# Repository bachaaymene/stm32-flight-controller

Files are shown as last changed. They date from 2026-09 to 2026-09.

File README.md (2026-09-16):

# STM32F405 Flight Controller

A 4-layer flight controller board for an F450 quadcopter frame, based on the STM32F405RGT6. Designed in KiCad 10 by [SparkLab DZ](https://sparklabdz.com).

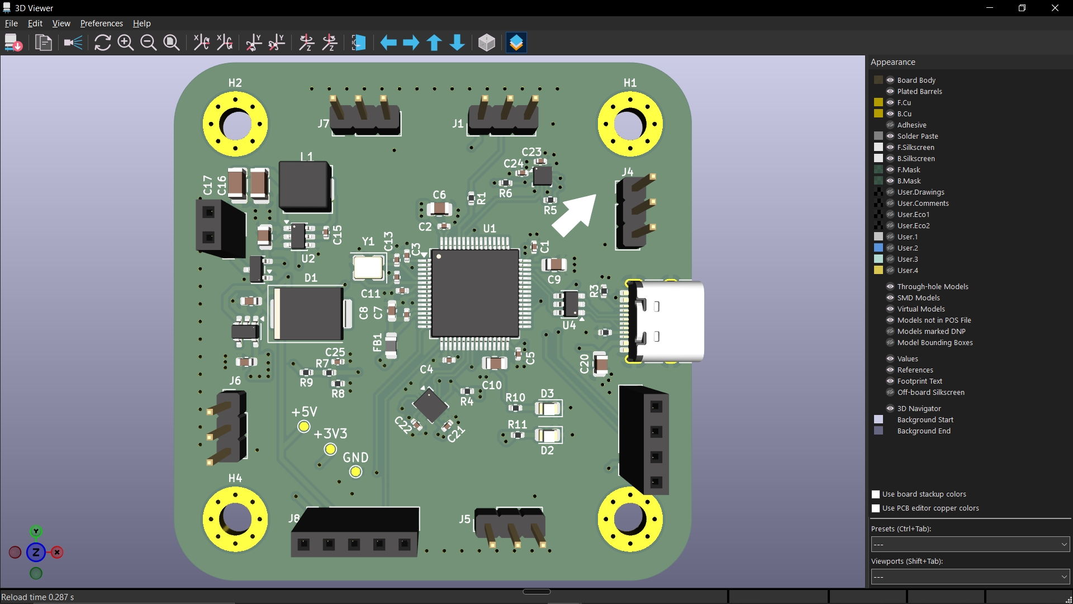
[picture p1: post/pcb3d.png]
3D render


## Features

| Block | Part | Notes |
|---|---|---|
| MCU | STM32F405RGT6 (LQFP64) | Cortex-M4F, 168 MHz, 1 MB Flash |
| IMU | LSM6DSO | SPI1, INT1 on PC4 |
| Barometer | LPS22HB | I2C1, address 0x5C |
| Motor outputs | 4x ESC | PC6 to PC9 on TIM3 (DShot capable) |
| 5V regulator | AP63205WU-7 | Synchronous buck, 3S LiPo input, 4.7 uH inductor |
| 3.3V regulator | TLV70233 | LDO from 5V |
| USB | USB Type-C 16P | PA11 / PA12 |
| Battery sense | 33k / 10k divider | PA0 (ADC) |

## Schematic

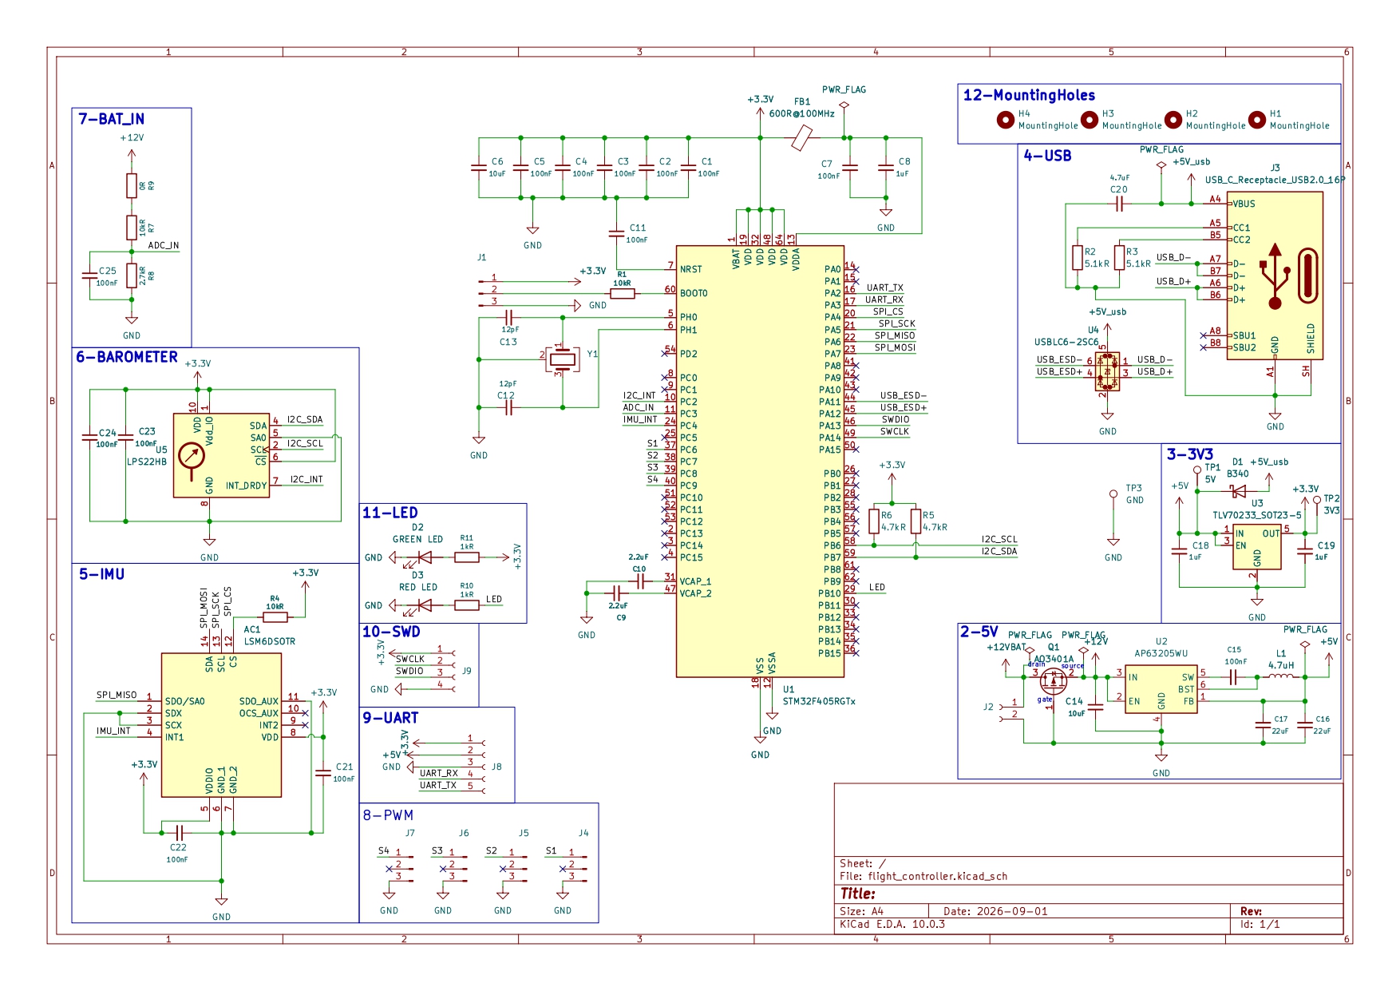
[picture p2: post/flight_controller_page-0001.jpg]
Schematic


Full schematic as PDF: [post/flight_controller.pdf](post/flight_controller.pdf)

## PCB Layout

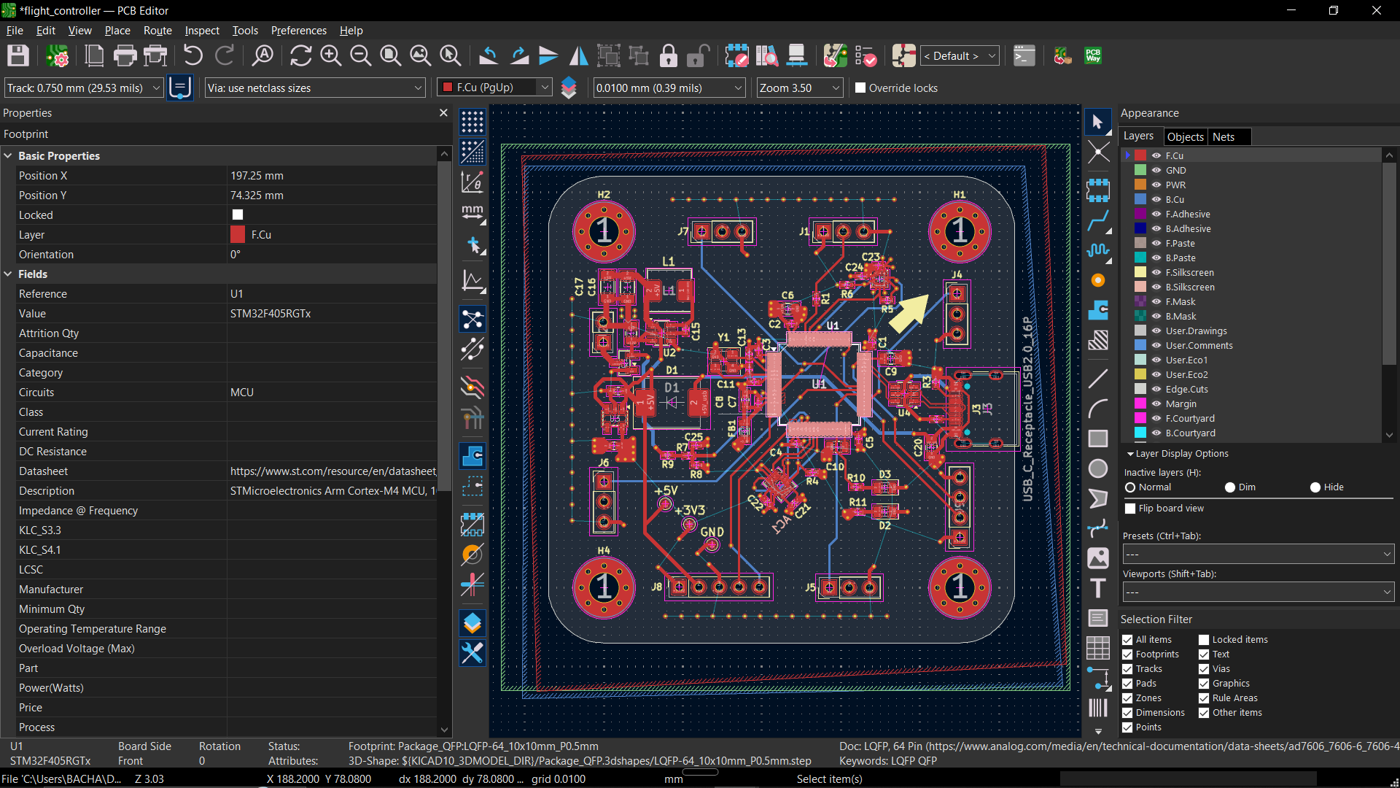
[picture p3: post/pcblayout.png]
PCB layout


### Stackup

| Layer | Use |
|---|---|
| L1 | Signal + components |
| L2 | Solid GND plane |
| L3 | Power |
| L4 | Signal |

## Pin Map

| Function | Pin(s) |
|---|---|
| IMU SPI1 (CS / SCK / MISO / MOSI) | PA4 / PA5 / PA6 / PA7 |
| IMU interrupt (INT1) | PC4 |
| Baro I2C1 (SCL / SDA) | PB6 / PB7 |
| ESC 1 to 4 | PC6 / PC7 / PC8 / PC9 |
| USB D- / D+ | PA11 / PA12 |
| Battery voltage | PA0 |

Pin configuration in STM32CubeIDE:

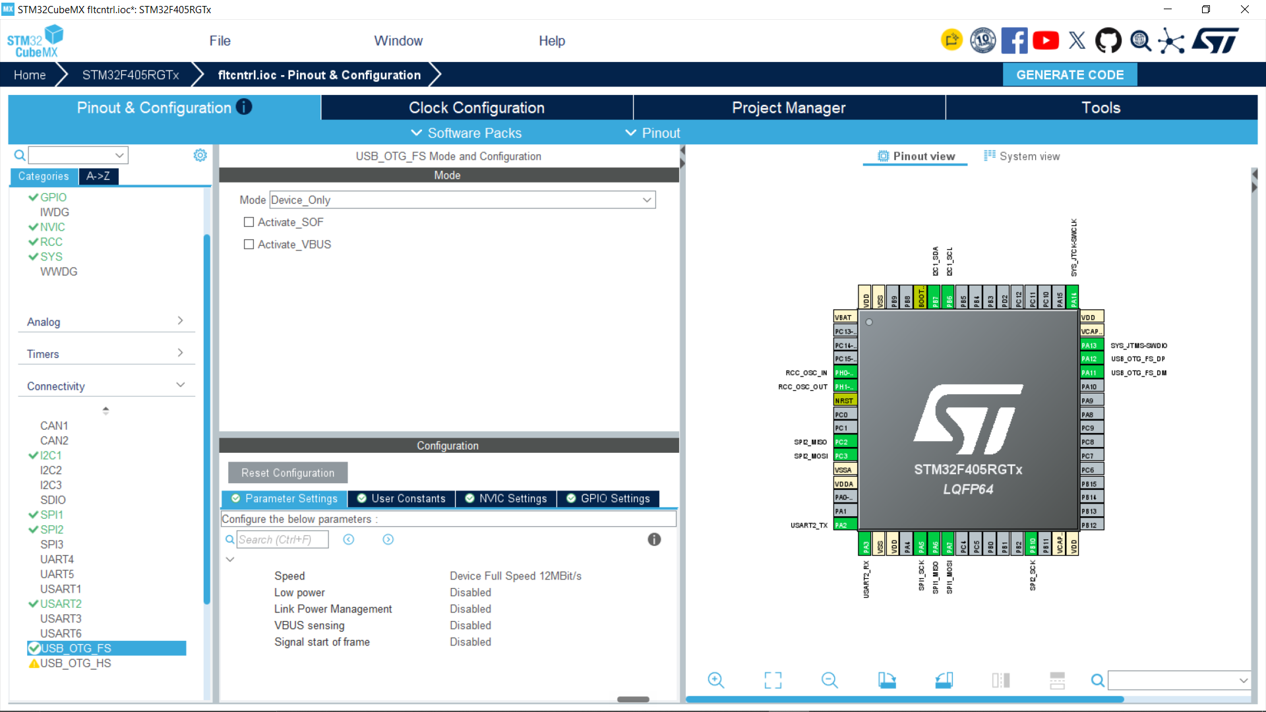
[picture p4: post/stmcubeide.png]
STM32CubeIDE pinout


## Repository Structure

```
stm32-flight-controller/
├── datasheets/                      Component datasheets
├── libs/                            Project symbols, footprints and 3D models
├── post/                            Schematic PDF and images
├── flight_controller.kicad_pro      KiCad project
├── flight_controller.kicad_sch      Schematic
├── flight_controller.kicad_pcb      PCB layout
├── flight_controller.csv            Bill of materials
├── fabrication-toolkit-options.json Fabrication Toolkit plugin settings
├── sym-lib-table                    Project symbol library table
├── fp-lib-table                     Project footprint library table
├── .gitattributes                   Git LFS settings
└── .gitignore
```

## Opening the Project

Requirements: **KiCad 10.0 or newer**. Older versions cannot open these files.

The repository uses Git LFS for large files, so install it before cloning:

```bash
git lfs install
git clone https://github.com/bachaaymene/stm32-flight-controller.git
```

Then open `flight_controller.kicad_pro` in KiCad.

All symbols, footprints and 3D models are stored in `libs/` with paths relative to the project (`${KIPRJMOD}`), so no external libraries are needed. If something appears missing, please open an issue.

## Manufacturing

The BOM is in `flight_controller.csv`.

Production files (Gerber, drill, BOM and CPL) for JLCPCB can be generated with the [Fabrication Toolkit](https://github.com/bennymeg/Fabrication-Toolkit) plugin. Install it from the KiCad Plugin and Content Manager, then run it from the PCB editor. The settings used for this board are saved in `fabrication-toolkit-options.json`.

## Status

- [x] Schematic
- [x] PCB layout
- [ ] Prototype fabrication
- [ ] Hardware bring-up
- [ ] Firmware

## License

This hardware design is released under the [CERN-OHL-S-2.0](LICENSE) license.

## Author

Aymene Bacha, [SparkLab DZ](https://sparklabdz.com)

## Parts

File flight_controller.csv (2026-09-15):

# | Reference | Qty | Manufacturer | Value | Description | Footprint | Circuits | LCSC
1 | AC1 | 1 |  | LSM6DSOTR | 6-axis IMU (inertial measurement unit): always-on 3axis accelerometer and 3axis gyroscope | Package_LGA:LGA-14_3x2.5mm_P0.5mm_LayoutBorder3x4y | IMU | C2655100
2 | C1,C2,C3,C4,C5,C7,C11,C15,C21,C22,C23,C24,C25 | 13 |  | 100nF | 100nF 0402 16V X7R | Capacitor_SMD:C_0402_1005Metric | Barometrer: Decoupling VDD,Barometrer: Decoupling VDDA,Bootstrap,Decoupling VBAT,Decoupling VDD,IMU: Decoupling VDD,IMU: Decoupling VDDA,NRST ,USB VBUS.,VDDA | C60474
3 | C6,C14 | 2 |  | 10uF | 10uF 0805 16V X5R,10uF 0805 25V X5R | Capacitor_SMD:C_0805_2012Metric | Buck input,Bulk Decoupling | C386085,C77075
4 | C8,C18,C19 | 3 |  | 1uF | 1uF 0603 16V X7R | Capacitor_SMD:C_0603_1608Metric | LDO input,LDO output,VDDA | C59782
5 | C9,C10 | 2 |  | 2.2uF | 2.2uF 0805 16V X5R | Capacitor_SMD:C_0805_2012Metric | Core regulator | C1731
6 | C12,C13 | 2 |  | 12pF | 12pF 0402 10V C0G | Capacitor_SMD:C_0402_1005Metric | Crystal load capacitors | C3899757
7 | C16,C17 | 2 |  | 22uF | 22uF 1206 25V X5R | Capacitor_SMD:C_1206_3216Metric | Buck output capacitors. | C7432785
8 | C20 | 1 |  | 4.7uF | 4.7uF 0805 16V X5R | Capacitor_SMD:C_0805_2012Metric | VBUS bulk | C1746
9 | D1 | 1 |  | B340 | 40V 3A Schottky Barrier Rectifier Diode, SMC | Diode_SMD:D_SMC | USB isolation | C388236
10 | D2 | 1 |  | GREEN LED | Light emitting diode | LED_SMD:LED_0805_2012Metric | Power indicator | C84260
11 | D3 | 1 |  | RED LED | Light emitting diode | LED_SMD:LED_0805_2012Metric | Status indicator | C2971979
12 | FB1 | 1 |  | 600R@100MHz | 300mR ±25% 600R@100MHz 0805 | Inductor_SMD:L_0805_2012Metric | VDDA isolation | C527966
13 | J1,J4,J5,J6,J7 | 5 |  | Conn_01x03_Pin | Generic connector, single row, 01x03, script generated | Connector_PinHeader_2.54mm:PinHeader_1x03_P2.54mm_Vertical | BOOT0,PWM
14 | J2 | 1 |  | Conn_01x02_Socket | Generic connector, single row, 01x02, script generated | Connector_PinSocket_2.54mm:PinSocket_1x02_P2.54mm_Vertical | Battery 12V
15 | J3 | 1 |  | USB_C_Receptacle_USB2.0_16P | USB 2.0-only 16P Type-C Receptacle connector | Connector_USB:USB_C_Receptacle_HRO_TYPE-C-31-M-12 | USB | C2988369
16 | J8 | 1 |  | Conn_01x05_Socket | Generic connector, single row, 01x05, script generated | Connector_PinSocket_2.54mm:PinSocket_1x05_P2.54mm_Vertical | UART
17 | J9 | 1 |  | Conn_01x04_Socket | Generic connector, single row, 01x04, script generated | Connector_PinSocket_2.54mm:PinSocket_1x04_P2.54mm_Vertical | SWD
18 | L1 | 1 |  | 4.7uH | 4.7uH, Isat 4.6A, DCR 60mR | Inductor_SMD:L_Sunlord_MWSA0503S | Buck inductor | C5349683
19 | Q1 | 1 |  | AO3401A | -4.0A Id, -30V Vds, P-Channel MOSFET, SOT-23 | Package_TO_SOT_SMD:SOT-23 | Reverse protection | C15127
20 | R1,R4,R7 | 3 |  | 10kR | 10kR 0402 | Resistor_SMD:R_0402_1005Metric | BOOT0,CS pull-up,Sense divider | C60490
21 | R2,R3 | 2 |  | 5.1kR | 5.1kR 0402 ±1% | Resistor_SMD:R_0402_1005Metric | CC pull-downs | C105872
22 | R5,R6 | 2 |  | 4.7kR | 4.7kR 0402 ±1% | Resistor_SMD:R_0402_1005Metric | I2C pull-ups | C105871
23 | R8 | 1 |  | 2.7kR | 2.7kR 0402 | Resistor_SMD:R_0402_1005Metric | Sense divider | C138017
24 | R9 | 1 |  | 0R | 0R 0402 | Resistor_SMD:R_0402_1005Metric | Sense isolation | C106231
25 | R10,R11 | 2 |  | 1kR | 1kR 0402 | Resistor_SMD:R_0402_1005Metric | LED current limit | C106235
26 | TP1 | 1 |  | 5V | test point | TestPoint:TestPoint_Pad_D1.0mm
27 | TP2 | 1 |  | 3V3 | test point | TestPoint:TestPoint_Pad_D1.0mm
28 | TP3 | 1 |  | GND | test point | TestPoint:TestPoint_Pad_D1.0mm
29 | U1 | 1 |  | STM32F405RGTx | STMicroelectronics Arm Cortex-M4 MCU, 1024KB flash, 192KB RAM, 168 MHz, 1.8-3.6V, 51 GPIO, LQFP64 | Package_QFP:LQFP-64_10x10mm_P0.5mm | MCU | C15742
30 | U2 | 1 |  | AP63205WU | 2A, 1.1MHz Buck DC/DC Converter, fixed 5.0V output voltage, TSOT-23-6 | Package_TO_SOT_SMD:TSOT-23-6 | 5V buck | C15742
31 | U3 | 1 |  | TLV70233_SOT23-5 | 300mA Low Dropout Voltage Regulator, Fixed Output 3.3V, SOT-23-5 | Package_TO_SOT_SMD:SOT-23-5 | 3V3 LDO | C26833
32 | U4 | 1 |  | USBLC6-2SC6 | Very low capacitance ESD protection diode, 2 data-line, SOT-23-6 | Package_TO_SOT_SMD:SOT-23-6 | USB ESD | C2827654
33 | U5 | 1 |  | LPS22HB | MEMS nano pressure sensor, 260-1260 hPa, absolute digital output baromeeter, 24 bit, SPI, I2C, 0.0075 hPa noise rms, ST_HLGA-10L | Package_LGA:ST_HLGA-10_2x2mm_P0.5mm_LayoutBorder3x2y | Pressure sensor | C94049
34 | Y1 | 1 |  | 8MHz Crystal_GND24 | 8MHz 10pF Four pin crystal, GND on pins 2 and 4 | Crystal:Crystal_SMD_3225-4Pin_3.2x2.5mm | HSE clock | C400090

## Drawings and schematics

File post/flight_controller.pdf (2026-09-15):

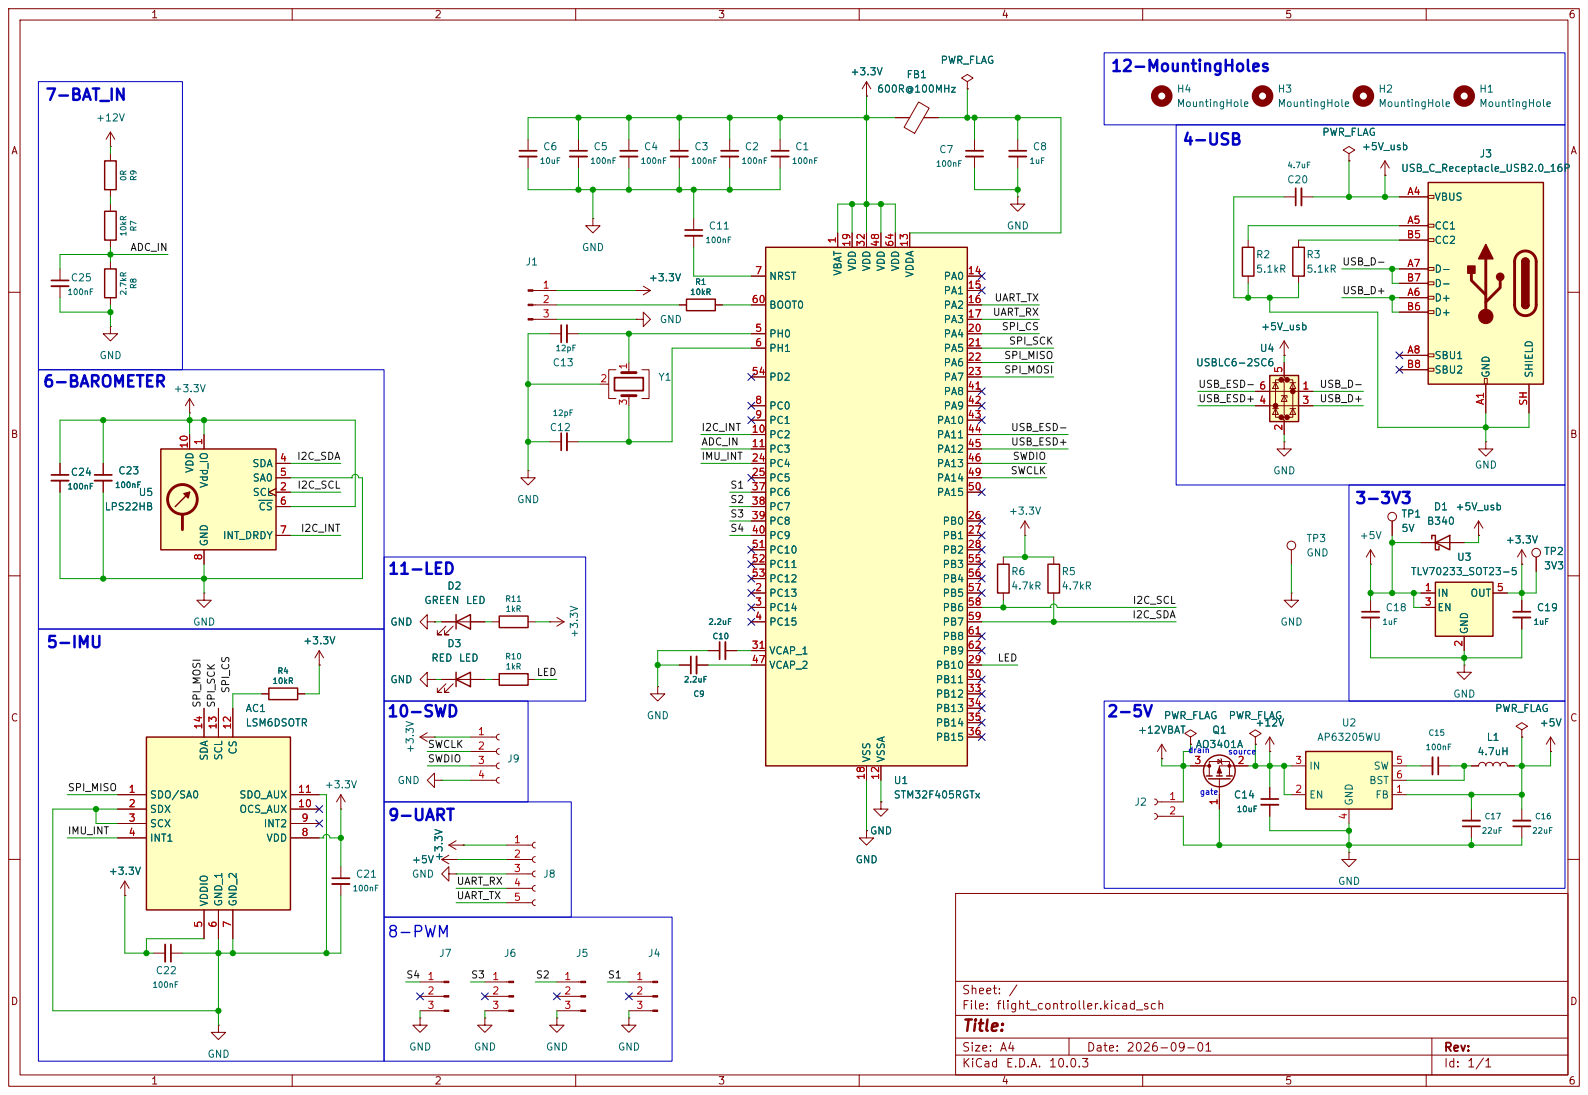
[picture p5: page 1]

Size: A4 | Rev:
KiCad E.D.A. 10.0.3 | Id: 1/1

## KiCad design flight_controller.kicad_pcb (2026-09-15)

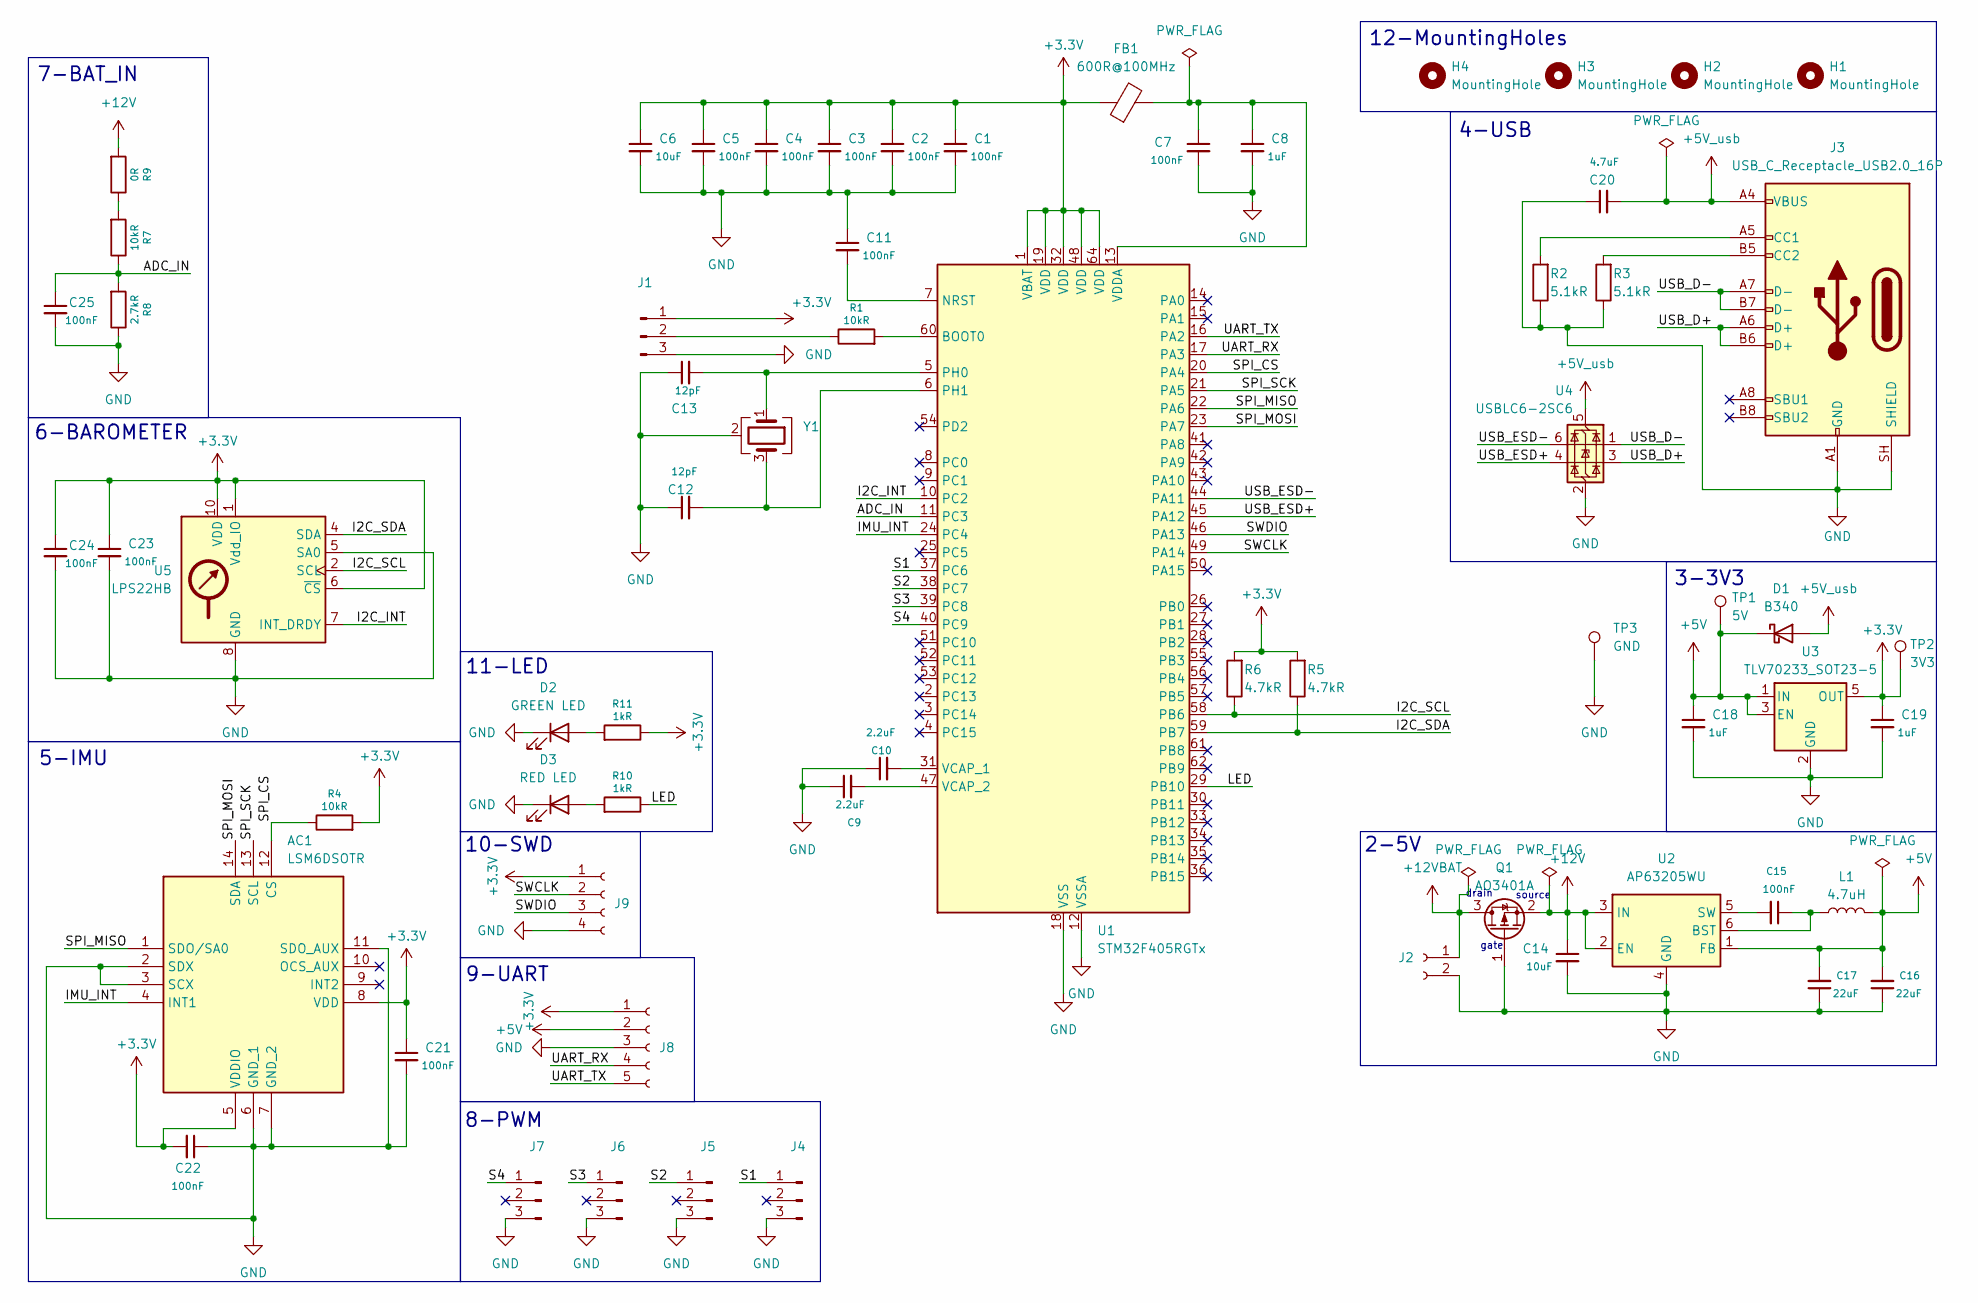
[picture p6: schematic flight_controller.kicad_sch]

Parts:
AC1: LSM6DSOTR; LGA-14_3x2.5mm_P0.5mm_LayoutBorder3x4y; Manufacturer_Part_Number LSM6DSOTR; Mouser Part Number 511-LSM6DSOTR
C1, C2, C3, C4, C5, C7, C11, C15, C21, C22, C23, C24, C25: 100nF; C_0402_1005Metric; LCSC C60474
C6: 10uF; C_0805_2012Metric; LCSC C77075
C8, C18, C19: 1uF; C_0603_1608Metric; LCSC C59782
C9, C10: 2.2uF; C_0805_2012Metric; LCSC C1731
C12, C13: 12pF; C_0402_1005Metric; LCSC C3899757
C14: 10uF; C_0805_2012Metric; LCSC C386085
C16, C17: 22uF; C_1206_3216Metric; LCSC C7432785
C20: 4.7uF; C_0805_2012Metric; LCSC C1746
D1: B340; D_SMC; LCSC C388236
D2: GREEN LED; LED_0805_2012Metric; LCSC C84260
D3: RED LED; LED_0805_2012Metric; LCSC C2971979
FB1: 600R@100MHz; L_0805_2012Metric; LCSC C527966
H1, H2, H3, H4: MountingHole; MountingHole_3.7mm_Pad_Via
J1, J4, J5, J6, J7: Conn_01x03_Pin; PinHeader_1x03_P2.54mm_Vertical
J2: Conn_01x02_Socket; PinSocket_1x02_P2.54mm_Vertical
J3: USB_C_Receptacle_USB2.0_16P; USB_C_Receptacle_HRO_TYPE-C-31-M-12; LCSC C2988369
J8: Conn_01x05_Socket; PinSocket_1x05_P2.54mm_Vertical
J9: Conn_01x04_Socket; PinSocket_1x04_P2.54mm_Vertical
L1: 4.7uH; L_Sunlord_MWSA0503S; LCSC C5349683
Q1: AO3401A; SOT-23; LCSC C15127
R1, R4, R7: 10kR; R_0402_1005Metric; LCSC C60490
R2, R3: 5.1kR; R_0402_1005Metric; LCSC C105872
R5, R6: 4.7kR; R_0402_1005Metric; LCSC C105871
R8: 2.7kR; R_0402_1005Metric; LCSC C138017
R9: 0R; R_0402_1005Metric; LCSC C106231
R10, R11: 1kR; R_0402_1005Metric; LCSC C106235
TP1: 5V; TestPoint_Pad_D1.0mm
TP2: 3V3; TestPoint_Pad_D1.0mm
TP3: GND; TestPoint_Pad_D1.0mm
U1: STM32F405RGTx; LQFP-64_10x10mm_P0.5mm; LCSC C15742
U2: AP63205WU; TSOT-23-6; LCSC C15742
U3: TLV70233_SOT23-5; SOT-23-5; LCSC C26833
U4: USBLC6-2SC6; SOT-23-6; LCSC C2827654
U5: LPS22HB; ST_HLGA-10_2x2mm_P0.5mm_LayoutBorder3x2y; LCSC C94049
Y1: 8MHz Crystal_GND24; Crystal_SMD_3225-4Pin_3.2x2.5mm; LCSC C400090

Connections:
+3.3V: AC1.5 (VDDIO), AC1.8 (VDD), C1.1, C2.1, C3.1, C4.1, C5.1, C6.1, C19.1, C21.1, C22.2, C23.1, C24.1, FB1.1, J1.1, J8.1, J9.1, R4.2, R5.2, R6.2, R11.1, TP2.1, U1.1 (VBAT), U1.19 (VDD), U1.32 (VDD), U1.48 (VDD), U1.64 (VDD), U3.5 (OUT), U5.1 (Vdd_IO), U5.6 (~CS), U5.10 (VDD); also elsewhere on the board
+5V: C16.2, C17.2, C18.1, D1.1 (K), J8.2, L1.2, TP1.1, U2.1 (FB), U3.1 (IN), U3.3 (EN); also elsewhere on the board
+5V_usb: C20.2, D1.2 (A), J3.A4 (VBUS), J3.A9 (VBUS), J3.B4 (VBUS), J3.B9 (VBUS), U4.5 (VBUS)
+12V: C14.1, Q1.2 (S), R9.2, U2.2 (EN), U2.3 (IN)
+12VBAT: J2.1, Q1.3 (D)
/ADC_IN: C25.1, R7.1, R8.2, U1.11 (PC3)
/I2C_INT: U1.10 (PC2), U5.7 (INT_DRDY)
/I2C_SCL: R6.1, U1.58 (PB6), U5.2 (SCL)
/I2C_SDA: R5.1, U1.59 (PB7), U5.4 (SDA)
/IMU_INT: AC1.4 (INT1), U1.24 (PC4)
/LED: R10.1, U1.29 (PB10)
/S1: J4.1, U1.37 (PC6)
/S2: J5.1, U1.38 (PC7)
/S3: J6.1, U1.39 (PC8)
/S4: J7.1, U1.40 (PC9)
/SPI_CS: AC1.12 (CS), R4.1, U1.20 (PA4)
/SPI_MISO: AC1.1 (SDO/SA0), U1.22 (PA6)
/SPI_MOSI: AC1.14 (SDA), U1.23 (PA7)
/SPI_SCK: AC1.13 (SCL), U1.21 (PA5)
/SWCLK: J9.2, U1.49 (PA14)
/SWDIO: J9.3, U1.46 (PA13)
/UART_RX: J8.4, U1.17 (PA3)
/UART_TX: J8.5, U1.16 (PA2)
/USB_D+: J3.A6 (D+), J3.B6 (D+), U4.3 (I/O2)
/USB_D-: J3.A7 (D-), J3.B7 (D-), U4.1 (I/O1)
/USB_ESD+: U1.45 (PA12), U4.4 (I/O2)
/USB_ESD-: U1.44 (PA11), U4.6 (I/O1)
GND: AC1.2 (SDX), AC1.3 (SCX), AC1.6 (GND_1), AC1.7 (GND_2), AC1.11 (SDO_AUX), C1.2, C2.2, C3.2, C4.2, C5.2, C6.2, C7.2, C8.2, C9.1, C10.1, C11.1, C12.1, C13.1, C14.2, C16.1, C17.1, C18.2, C19.2, C20.1, C21.2, C22.1, C23.2, C24.2, C25.2, D2.1 (K), D3.1 (K), J1.3, J2.2, J3.A1 (GND), J3.A12 (GND), J3.B1 (GND), J3.B12 (GND), J3.SH (SHIELD), J4.3, J5.3, J6.3, J7.3, J8.3, J9.4, Q1.1 (G), R2.1, R3.1, R8.1, TP3.1, U1.12 (VSSA), U1.18 (VSS), U1.63 (VSS), U2.4 (GND), U3.2 (GND), U4.2 (GND), U5.3 (GND), U5.5 (SA0), U5.8 (GND), U5.9 (GND), Y1.2 (G), Y1.4 (G); also elsewhere on the board
unnamed: D2.2 (A), R11.2
unnamed: D3.2 (A), R10.2
unnamed: J1.2, R1.1
unnamed: J3.A5 (CC1), R2.2
unnamed: J3.B5 (CC2), R3.2
unnamed: R7.2, R9.1
unnamed: R1.2, U1.60 (BOOT0)
unnamed: C11.2, U1.7 (NRST)
unnamed: C13.2, U1.5 (PH0), Y1.1
unnamed: C12.2, U1.6 (PH1), Y1.3
unnamed: C10.2, U1.31 (VCAP_1)
unnamed: C9.2, U1.47 (VCAP_2)
unnamed: C7.1, C8.1, FB1.2, U1.13 (VDDA)
unnamed: C15.1, L1.1, U2.6 (BST)
unnamed: C15.2, U2.5 (SW)

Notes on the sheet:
source
2-5V
gate
3-3V3
4-USB
7-BAT_IN
6-BAROMETER
12-MountingHoles
10-SWD
5-IMU
8-PWM
drain
9-UART
11-LED

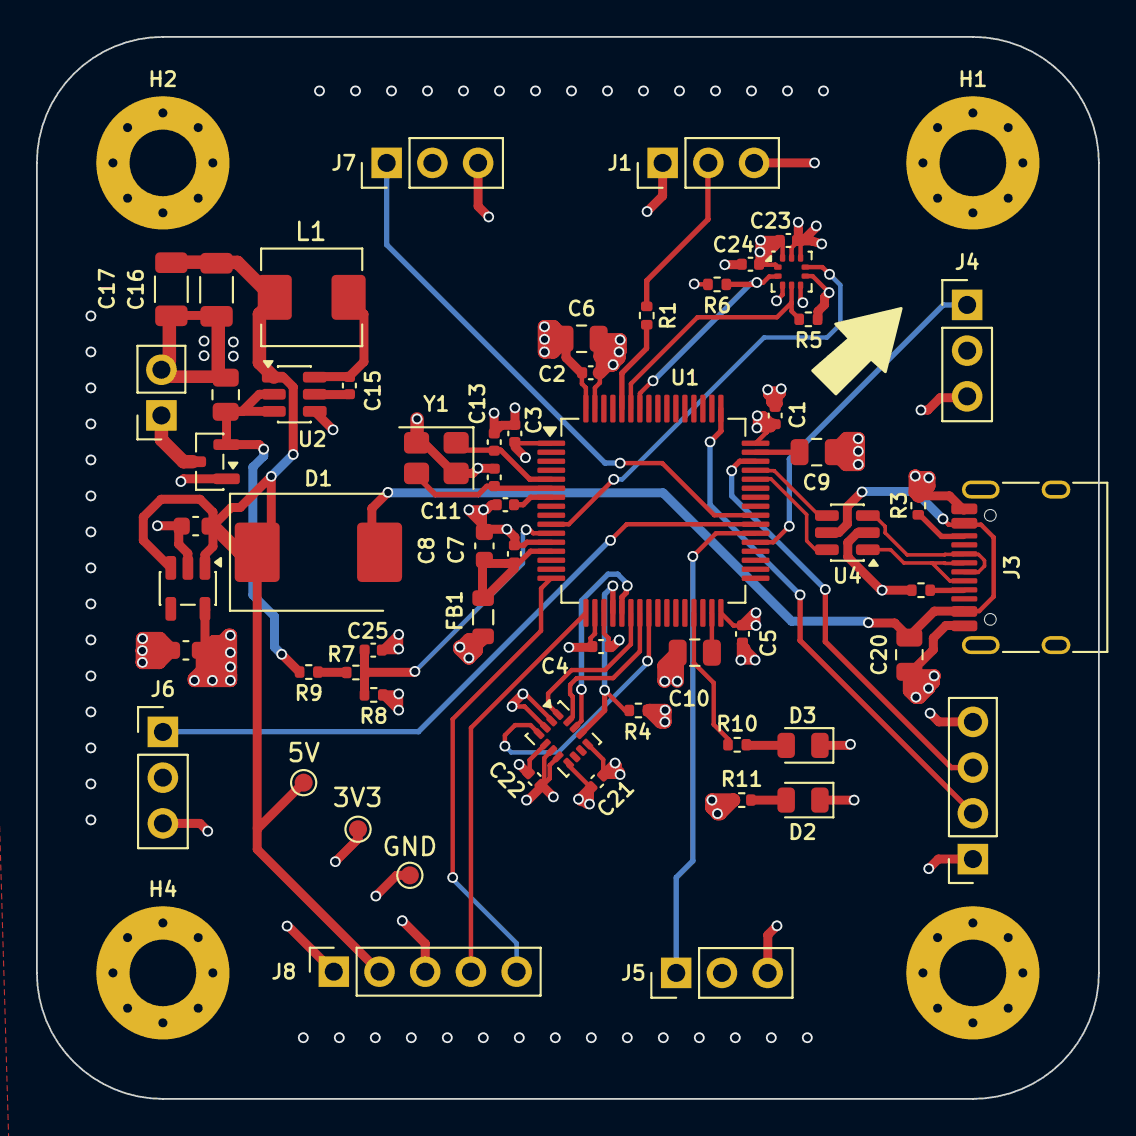
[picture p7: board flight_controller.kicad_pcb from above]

Board: 4 copper layers, 59.0 x 59.0 mm, 65 parts (0 on the bottom side), 43 nets.

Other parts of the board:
3V3: 3V3; TestPoint_Pad_D1.0mm
5V: 5V; TestPoint_Pad_D1.0mm
GND: GND; TestPoint_Pad_D1.0mm

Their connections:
+3.3V: 3V3.1 (1_1); also elsewhere on the board
+5V: 5V.1 (1_1); also elsewhere on the board
GND: GND.1 (1_1); also elsewhere on the board

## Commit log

2026-09-15 Backup: project state before library self-containment
    Snapshot of the flight_controller KiCad 10 project as it stands before
    vendoring 3D models, symbols and footprints into project-local libraries.
    [flight_controller.csv, flight_controller.kicad_pcb, flight_controller.kicad_sch]
2026-09-16 Add README for STM32F405 Flight Controller
    Add detailed README for STM32F405 flight controller, including features, pin map, PCB stackup, repository structure, project opening instructions, manufacturing details, status, license, and author i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
2026-09-16 Revise README with new images and additional sections
    Updated images and added schematic and PCB layout sections.
